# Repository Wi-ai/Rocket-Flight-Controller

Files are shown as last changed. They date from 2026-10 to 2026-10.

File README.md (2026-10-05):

# Rocket-Flight-Controller
this is a prototype flight controller for the rocket am building

pcd the gnd
PCB
MicroSDCard
Battery Charger
3D view
3 3V buck


Shipping price
shipping details 2
shipping details 1

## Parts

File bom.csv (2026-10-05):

Designator | Footprint | Quantity | Value | LCSC Part #
C1, C28, C29, C30 | 0402 | 4 | 1uF
C10, C11, C13 | 0805 | 3 | 22uF
C12, C2, C9 | 0603 | 3 | 10uF
C14, C15, C19, C20, C23, C24, C25, C26, C27, C37 | 0201 | 10 | 100nF
C16 | 0603 | 1 | 2.2uF
C17, C18 | 0402 | 2 | 22uF
C21, C22 | 0201 | 2 | 0.1uF
C3, C31, C5 | 0402 | 3 | 10uF
C32 | 0201 | 1 | 2.2uF
C33, C34 | 0201 | 2 | 20pF
C35, C36 | 0201 | 2 | 6.8pF
C4 | 0201 | 1 | 47nF
C6 | 0603 | 1 | 44uF
C7, C8 | 0805 | 2 | 10uF
CARD1 | TF-SMD_TF-01A | 1 | TF-01A | C91145
D1 | 0402 | 1 | LED
J1 | TerminalBlock_Xinya_XY308-2.54-2P_1x02_P2.54mm_Horizontal | 1 | Screw_Terminal_01x02
J2, J3 | PinHeader_1x03_P2.54mm_Vertical | 2 | Conn_01x03
L1 | L2520 | 1 | DFE252012F-1R0M=P2 | C435392
L2 | IND-SMD_L4.0-W4.0-A | 1 | 1.5uH | C3033018
L4 | L0603 | 1 | FCM1608KF-601T03 | C141723
L7 | IND-SMD_L3.0-W3.0 | 1 | 5.6uH | C18236327
R1, R2 | 0201 | 2 | 5.1K
R10, R11, R12, R13, R16, R17, R18, R19, R20, R21, R22, R6, R7, R8, R9 | 0201 | 15 | 10K
R14 | 0402 | 1 | 100K
R15 | 0402 | 1 | 22.1K
R3 | 0201 | 1 | 3B3
R4 | 0201 | 1 | 5.23K
R5 | 0201 | 1 | 30.1K
SW1, SW2 | SW-SMD_L3.9-W3.0-P4.45 | 2 | TS-1088-AR02016 | C720477
U1 | LQFP-64_10x10mm_P0.5mm | 1 | STM32F722RETx
U2 | VFQFPN-24_L4.0-W4.0-P0.50-BL-EP2.8 | 1 | BQ25883RGER | C544362
U3 | LGA-10_L2.0-W2.0-P0.50-TL_BMP580 | 1 | BMP580 | C22391138
U4 | LGA-14_L3.0-W2.5-P0.50-TL | 1 | ICM-45686 | C22459454
U5 | VQFN-HR-15_L3.0-W2.5-P0.50-BL_TPS63070RNMR | 1 | TPS63070RNMR | C109322
U6 | SOT-23-6 | 1 | LMR51430
USB1 | USB-C-SMD_TYPE-C-6PIN-2MD-073 | 1 | TYPE-C 16PIN 2MD(073) | C2765186
X1 | CRYSTAL-SMD_4P-L3.2-W2.5-BL | 1 | X322525MOB4SI | C9006
X2 | FC-135R_L3.2-W1.5 | 1 | Q13FC1350000400 | C32346

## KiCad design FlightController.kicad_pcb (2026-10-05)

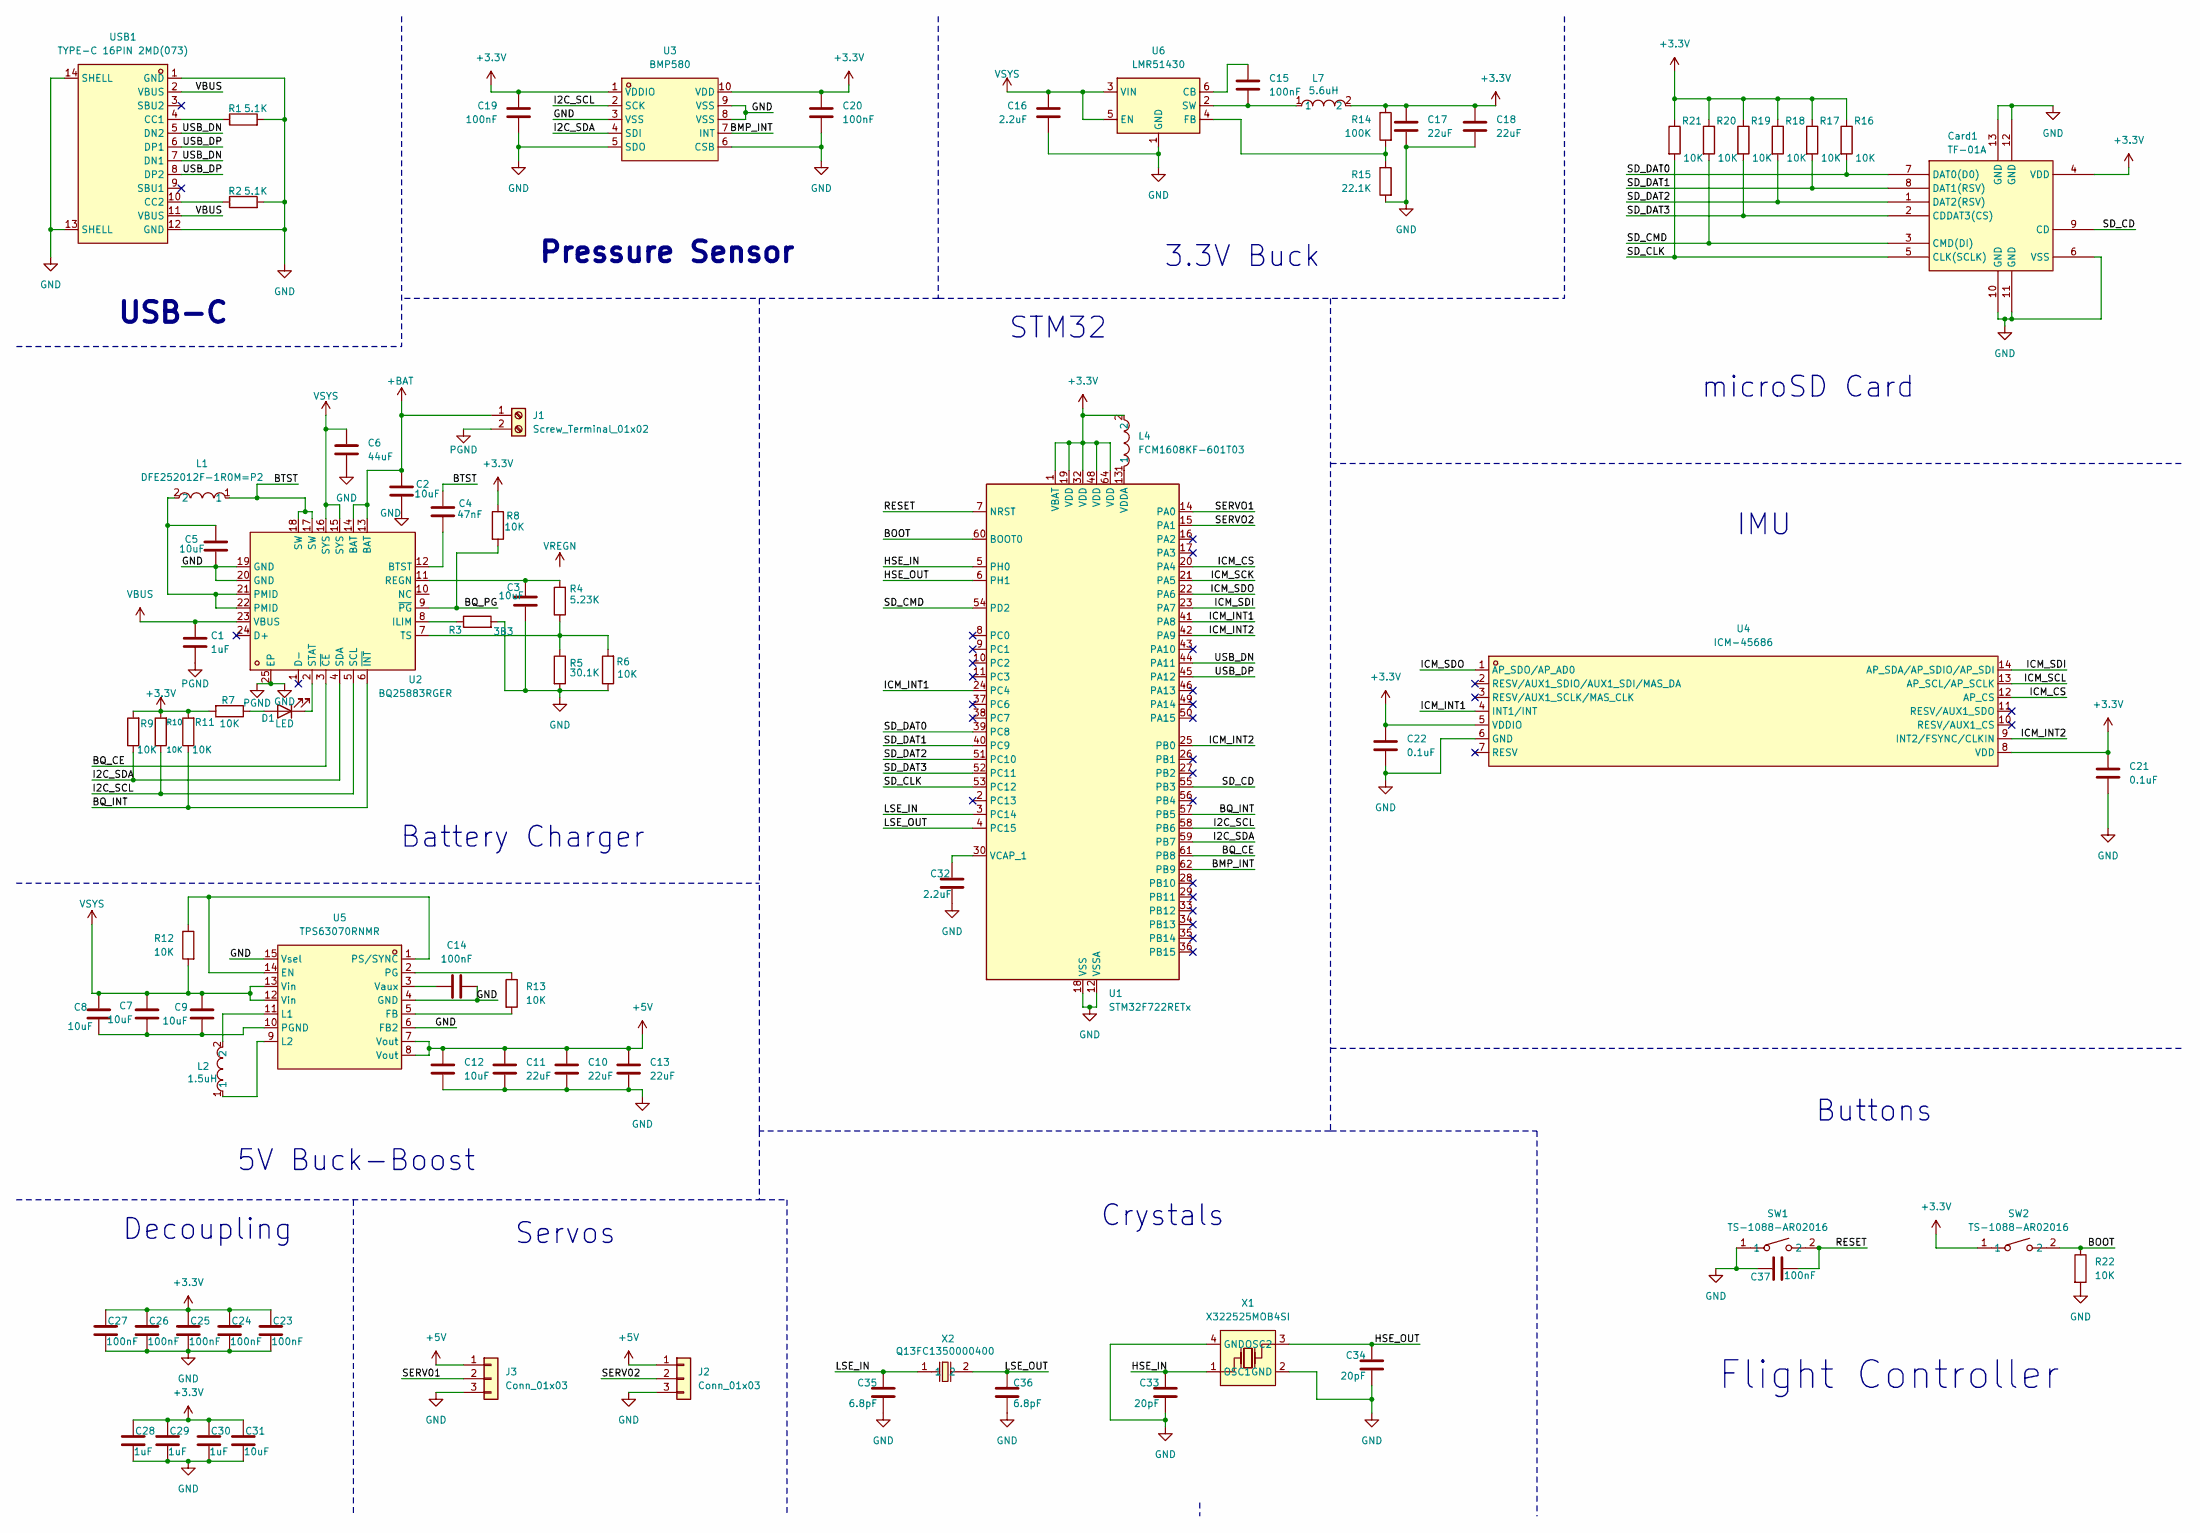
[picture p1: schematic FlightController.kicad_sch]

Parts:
C1, C28, C29, C30: 1uF; C_0402_1005Metric
C2, C9, C12: 10uF; C_0603_1608Metric
C3, C5, C31: 10uF; C_0402_1005Metric
C4: 47nF; C_0201_0603Metric
C6: 44uF; C_0603_1608Metric
C7, C8: 10uF; C_0805_2012Metric
C10, C11, C13: 22uF; C_0805_2012Metric
C14, C15, C19, C20, C23, C24, C25, C26, C27, C37: 100nF; C_0201_0603Metric
C16: 2.2uF; C_0603_1608Metric
C17, C18: 22uF; C_0402_1005Metric
C21, C22: 0.1uF; C_0201_0603Metric
C32: 2.2uF; C_0201_0603Metric
C33, C34: 20pF; C_0201_0603Metric
C35, C36: 6.8pF; C_0201_0603Metric
Card1: TF-01A; TF-SMD_TF-01A; LCSC Part C91145
D1: LED; LED_0402_1005Metric
J1: Screw_Terminal_01x02; TerminalBlock_Xinya_XY308-2.54-2P_1x02_P2.54mm_Horizontal
J2, J3: Conn_01x03; PinHeader_1x03_P2.54mm_Vertical
L1: DFE252012F-1R0M=P2; L2520; LCSC Part C435392
L2: 1.5uH; IND-SMD_L4.0-W4.0-A; LCSC Part C3033018
L4: FCM1608KF-601T03; L0603; LCSC Part C141723
L7: 5.6uH; IND-SMD_L3.0-W3.0; LCSC Part C18236327
R1, R2: 5.1K; R_0201_0603Metric
R3: 3B3; R_0201_0603Metric
R4: 5.23K; R_0201_0603Metric
R5: 30.1K; R_0201_0603Metric
R6, R7, R8, R9, R10, R11, R12, R13, R16, R17, R18, R19, R20, R21, R22: 10K; R_0201_0603Metric
R14: 100K; R_0402_1005Metric
R15: 22.1K; R_0402_1005Metric
SW1, SW2: TS-1088-AR02016; SW-SMD_L3.9-W3.0-P4.45; LCSC Part C720477
U1: STM32F722RETx; LQFP-64_10x10mm_P0.5mm
U2: BQ25883RGER; VFQFPN-24_L4.0-W4.0-P0.50-BL-EP2.8; LCSC Part C544362
U3: BMP580; LGA-10_L2.0-W2.0-P0.50-TL_BMP580; LCSC Part C22391138
U4: ICM-45686; LGA-14_L3.0-W2.5-P0.50-TL; LCSC Part C22459454
U5: TPS63070RNMR; VQFN-HR-15_L3.0-W2.5-P0.50-BL_TPS63070RNMR; LCSC Part C109322
U6: LMR51430; SOT-23-6
USB1: TYPE-C 16PIN 2MD(073); USB-C-SMD_TYPE-C-6PIN-2MD-073; LCSC Part C2765186
X1: X322525MOB4SI; CRYSTAL-SMD_4P-L3.2-W2.5-BL; LCSC Part C9006
X2: Q13FC1350000400; FC-135R_L3.2-W1.5; LCSC Part C32346

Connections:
+3.3V: C17.1, C18.1, C19.1, C20.1, C21.1, C22.1, C23.1, C24.1, C25.1, C26.1, C27.1, C28.1, C29.1, C30.1, C31.1, Card1.4 (VDD), L4.2, L7.2, R7.2, R8.1, R9.2, R10.2, R11.2, R14.1, R16.1, R17.1, R18.1, R19.1, R20.1, R21.1, SW2.1, U1.1 (VBAT), U1.19 (VDD), U1.32 (VDD), U1.48 (VDD), U1.64 (VDD), U3.1 (VDDIO), U3.10 (VDD), U4.5 (VDDIO), U4.8 (VDD)
+5V: C10.1, C11.1, C12.1, C13.1, J2.1, J3.1, U5.7 (Vout), U5.8 (Vout)
+BAT: C2.1, J1.1, U2.13 (BAT), U2.14 (BAT)
/BMP_INT: U1.62 (PB9), U3.7 (INT)
/BOOT: R22.1, SW2.2, U1.60 (BOOT0)
/BQ_CE: U1.61 (PB8), U2.3 (~CE)
/BQ_INT: R11.1, U1.57 (PB5), U2.6 (~INT)
/BQ_PG: R8.2, U2.9 (~PG)
/BTST: C4.1, L1.1, U2.17 (SW), U2.18 (SW)
/HSE_IN: C33.1, U1.5 (PH0), X1.1 (OSC1)
/HSE_OUT: C34.1, U1.6 (PH1), X1.3 (OSC2)
/I2C_SCL: R10.1, U1.58 (PB6), U2.5 (SCL), U3.2 (SCK)
/I2C_SDA: R9.1, U1.59 (PB7), U2.4 (SDA), U3.4 (SDI)
/ICM_CS: U1.20 (PA4), U4.12 (AP_CS)
/ICM_INT1: U1.24 (PC4), U1.41 (PA8), U4.4 (INT1/INT)
/ICM_INT2: U1.25 (PB0), U1.42 (PA9), U4.9 (INT2/FSYNC/CLKIN)
/ICM_SCK: U1.21 (PA5)
/ICM_SCL: U4.13 (AP_SCL/AP_SCLK)
/ICM_SDI: U1.23 (PA7), U4.14 (AP_SDA/AP_SDIO/AP_SDI)
/ICM_SDO: U1.22 (PA6), U4.1 (AP_SDO/AP_AD0)
/LSE_IN: C35.1, U1.3 (PC14), X2.1
/LSE_OUT: C36.1, U1.4 (PC15), X2.2
/RESET: C37.2, SW1.2, U1.7 (NRST)
/SD_CD: Card1.9 (CD), U1.55 (PB3)
/SD_CLK: Card1.5 (CLK(SCLK)), R21.2, U1.53 (PC12)
/SD_CMD: Card1.3 (CMD(DI)), R20.2, U1.54 (PD2)
/SD_DAT0: Card1.7 (DAT0(D0)), R16.2, U1.39 (PC8)
/SD_DAT1: Card1.8 (DAT1(RSV)), R17.2, U1.40 (PC9)
/SD_DAT2: Card1.1 (DAT2(RSV)), R18.2, U1.51 (PC10)
/SD_DAT3: Card1.2 (CDDAT3(CS)), R19.2, U1.52 (PC11)
/SERV01: J3.2
/SERV02: J2.2
/SERVO1: U1.14 (PA0)
/SERVO2: U1.15 (PA1)
/USB_DN: U1.44 (PA11), USB1.5 (DN2), USB1.7 (DN1)
/USB_DP: U1.45 (PA12), USB1.6 (DP1), USB1.8 (DP2)
GND: C1.2, C2.2, C3.2, C5.2, C6.2, C10.2, C11.2, C12.2, C13.2, C14.2, C16.2, C17.2, C18.2, C19.2, C20.2, C21.2, C22.2, C23.2, C24.2, C25.2, C26.2, C27.2, C28.2, C29.2, C30.2, C31.2, C32.2, C33.2, C34.2, C35.2, C36.2, C37.1, Card1.6 (VSS), Card1.10 (GND), Card1.11 (GND), Card1.12 (GND), Card1.13 (GND), J1.2, J2.3, J3.3, R1.2, R2.2, R3.2, R5.2, R6.1, R15.2, R22.2, SW1.1, U1.12 (VSSA), U1.18 (VSS), U1.31 (VSS), U1.47 (VSS), U1.63 (VSS), U2.19 (GND), U2.20 (GND), U2.25 (EP), U3.3 (VSS), U3.5 (SDO), U3.6 (CSB), U3.8 (VSS), U3.9 (VSS), U4.6 (GND), U5.4 (GND), U5.6 (FB2), U5.15 (Vsel), U6.1 (GND), USB1.1 (GND), USB1.12 (GND), USB1.13 (SHELL), USB1.14 (SHELL), X1.2 (GND), X1.4 (GND)
unnamed: C5.1, L1.2, U2.21 (PMID), U2.22 (PMID)
unnamed: D1.2 (A), R7.1
unnamed: D1.1 (K), U2.2 (STAT)
unnamed: C32.1, U1.30 (VCAP_1)
unnamed: L4.1, U1.13 (VDDA)
unnamed: C4.2, U2.12 (BTST)
unnamed: R3.1, U2.8 (ILIM)
unnamed: C3.1, R4.2, U2.11 (REGN)
unnamed: R4.1, R5.1, R6.2, U2.7 (TS)
unnamed: R12.1, U5.1 (PS/SYNC), U5.14 (EN)
unnamed: R13.2, U5.5 (FB)
unnamed: L2.2, U5.11 (L1)
unnamed: L2.1, U5.9 (L2)
unnamed: R13.1, U5.2 (PG)
unnamed: C7.2, C8.2, C9.2, U5.10 (PGND)
unnamed: C14.1, U5.3 (Vaux)
unnamed: C15.1, U6.6 (CB)
unnamed: R14.2, R15.1, U6.4 (FB)
unnamed: C15.2, L7.1, U6.2 (SW)
unnamed: R1.1, USB1.4 (CC1)
unnamed: R2.1, USB1.10 (CC2)
VBUS: C1.1, U2.23 (VBUS), USB1.2 (VBUS), USB1.11 (VBUS)
VSYS: C6.1, C7.1, C8.1, C9.1, C16.1, R12.2, U2.15 (SYS), U2.16 (SYS), U5.12 (Vin), U5.13 (Vin), U6.3 (VIN), U6.5 (EN)

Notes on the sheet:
Buttons
Pressure Sensor
Battery Charger
IMU
USB-C
5V Buck-Boost
3.3V Buck
Decoupling
Servos
Flight Controller
Crystals
microSD Card
STM32

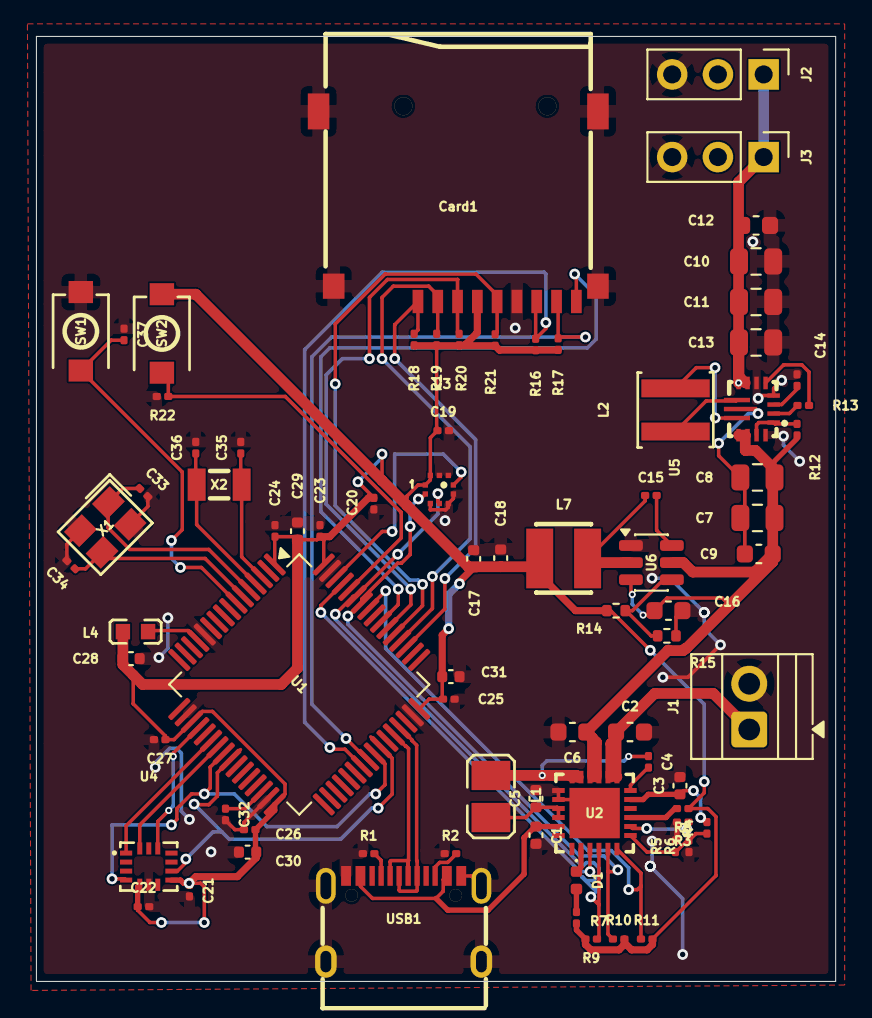
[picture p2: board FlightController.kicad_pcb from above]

Board: 2 copper layers, 44.4 x 52.5 mm, 79 parts (0 on the bottom side), 54 nets.
